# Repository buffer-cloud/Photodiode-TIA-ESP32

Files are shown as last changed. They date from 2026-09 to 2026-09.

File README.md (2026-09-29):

# Photodiode TIA + ESP32 Optical Sensor

Photodiode transimpedance amplifier with ESP32 wireless acquisition and Python-based signal analysis. The analog noise budget is quantified in µV (CALCULATED); end-to-end resolution is expected to be limited by the ESP32 ADC, so no system-level "low-noise" claim is made until measured.

**Status:** Revision A analog design and simulation gate PASS; schematic, PCB, firmware and Python tools complete. The BOM and fabrication exports are complete for bare-board prototype fabrication. Component qualification and physical validation remain pending. BPW34 remains the provisional detector. All physical results are **TBD — HARDWARE MEASUREMENT REQUIRED**. See [implementation verification](docs/implementation-verification.md), [manufacturing notes](hardware/manufacturing/rev-a/fabrication-notes.md) and the [bring-up plan](docs/bringup-plan.md).

## Repository structure

- `docs/`: requirements, architecture, calculations and verification
- `simulation/`: LTspice circuits and reproducible analysis
- `hardware/`: KiCad design, BOM and manufacturing notes
- `firmware/esp32/`: acquisition and WebSocket telemetry
- `software/python/`: dashboard and analysis
- `measurements/`: real bench data only
- `portfolio/`: case study and factual résumé entry

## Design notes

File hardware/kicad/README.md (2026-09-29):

# Photodiode TIA / ESP32 — native KiCad 9

Open `photodiode-tia-esp32.kicad_pro`. The native schematic is the editable source of truth. It uses one A3 sheet with supply, reference, bypass, detector/TIA, paired gain branches, buffered filter/ADC and test-point sections. `Photodiode.kicad_sym` and both library tables are project-relative; install standard KiCad 9 footprint libraries.

`verification/pin-review.md` records manufacturer pin checks and executed ERC/export checks. Generated `verification/schematic.xml`, `schematic.pdf`, and `erc.rpt` are local review outputs and can be regenerated with KiCad CLI.

`build_schematic.py` preserves the initial capture recipe, not an automatic synchronization mechanism. It refuses to replace an existing schematic unless `--overwrite` is explicitly passed. **That flag discards manual schematic/library edits.** Make a backup or use a separate checkout first. Symbol-library discovery supports `--symbol-library PATH`, `KICAD_SYMBOL_DIR`, then conventional Linux/macOS/Windows KiCad 9 installation paths. The checked-in native schematic does not require Python or this recipe to open/edit.

The custom Vishay BPW34 footprint defines pin1=cathode, pin2=anode, 5.1 mm pitch; see the pin-review evidence. No PCB is created by this capture recipe.

Operate with exactly one gain shunt. Power off before changing it. Open JP_ADC for independent powering; clamps are not powered-off isolation. Prototype checks and rail-ramp verification are required before connecting the ADC link.

## Routed PCB

The native PCB is fully routed on two layers, 60 × 45 mm, 1.6 mm thick. Executed all-severity DRC with schematic parity passes with zero violations, zero unconnected items and zero parity issues; see `verification/drc.rpt` and `verification/layout-review.md`. `verification/board-top.png` is the reviewed top rendering. `verification/assembly-top.svg` supplies visible numeric component references. Vias are off SMD pads; manufacturing-output review and bench-validation limits are documented in the layout review.

Use the saved PCB as the authoritative design. `repair_pcb.py --output NEW_PATH` creates a separate candidate without overwriting any existing file. The native project does not run this script on opening. The defective initial routing recipe and intermediate candidates are retained only in ignored local recovery storage.

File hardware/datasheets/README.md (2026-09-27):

# Manufacturer references and provisional photodiode model

Links checked 2026-09-26; fetch current manufacturer copies before ordering. Manufacturer models and PDFs are not redistributed here.

- [Vishay BPW34 datasheet](https://www.vishay.com/docs/81521/bpw34.pdf): reverse dark current 2 nA typ/30 nA max at 10 V; capacitance 70 pF typ at 0 V, 25 pF typ/40 pF max at 3 V, 1 MHz. Neither specifies the exact 1.65 V operating point. Verify cathode marking and lead spacing from package drawing before assembly.
- [TI OPA320/OPA2320 datasheet SBOS513F](https://www.ti.com/lit/ds/symlink/opa320.pdf): electrical table, SOIC-8 pinout, TIA application guidance; 5 pF differential plus 4 pF common-mode input capacitance.
- [TI OPA380 datasheet SBOS291G](https://www.ti.com/lit/ds/symlink/opa380.pdf): comparison only.
- [TI OPA381 datasheet SBOS313B](https://www.ti.com/lit/ds/symlink/opa381.pdf): comparison only.
- [Espressif original ESP32 ADC guide](https://docs.espressif.com/projects/esp-idf/en/v4.4/esp32/api-reference/peripherals/adc.html): ADC1, attenuation and calibration; use 150–2450 mV recommended window at 11 dB.

Provisional circuit model: independent photocurrent source from cathode (3V3A) toward anode (SUM), parallel diode capacitance and independently parameterized dark current. CT=80 pF nominal includes diode+amplifier+PCB; sweep 40/80/120 pF. Do not double-count amplifier capacitance when using a vendor model that already includes it. A fixed capacitance/current-source model does not predict avalanche, wavelength responsivity, temperature, nonlinear junction capacitance or overload recovery. The 2 nA dark scenario is illustrative, not a guarantee at our bias. Replace it with measured C(V), dark current and optical calibration for the actual photodiode. No arbitrary diode saturation-current model should be presented as a manufacturer model.

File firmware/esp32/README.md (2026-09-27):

# ESP32 acquisition firmware

This salvages the initial implementation using the Arduino 2 APIs supplied by the pinned PlatformIO platform. Target: original ESP32 DevKit (`esp32dev`), GPIO34 / ADC1 channel 6, 12 bits, 11 dB attenuation. No analog or protocol interfaces are changed.

## Reproducible build and use

Tested with PlatformIO Core **6.2.0**. `platformio.ini` pins `espressif32@7.1.3`, framework package `platformio/framework-arduinoespressif32@3.20017.241212` (Arduino **2.0.17**) and WebSockets **2.7.3**. Do not substitute Arduino 3 GPTimer/oneshot headers into this build.

From the repository root:

```sh
python3 -m venv .venv
.venv/bin/python -m pip install platformio==6.2.0
.venv/bin/pio run -d firmware/esp32
cp firmware/esp32/include/secrets.example.h firmware/esp32/include/secrets.h
# Edit secrets.h locally with your Wi-Fi credentials.
.venv/bin/pio run -d firmware/esp32 -t upload
.venv/bin/pio device monitor -d firmware/esp32
```

Skip environment creation if `.venv` already exists. A clean checkout builds without credentials using the placeholder example header; real Wi-Fi requires the local `secrets.h`, ignored by the root `.gitignore`. Never commit credentials. Serial is **115200 baud**, newline-terminated commands. The IP is printed after connection. Connect a client to `ws://<esp32-ip>:81/`; other paths are rejected. Plain WebSocket is intended for a trusted local network.

Commands: `help`, `status`, `rate 1000` through `rate 8000`, `gain 10000|100000|1000000`, `avg 1` through `avg 64`, `dcrm on|off`, `print 20`, `wifi on|off`. Default rate is 4000 Hz and gain metadata is 100000 ohms. Rate requests take effect at a batch boundary; status reports the requested rate. Gain metadata is captured at the first sample of each batch. Change physical gain only with power off and exactly one feedback pair selected; the command does not switch hardware. Average/DC removal affect serial diagnostics only.

## Timing, calibration and loss behavior

A 40 MHz hardware timer (APB divider 2) wakes a high-priority task on core 1. ADC conversion occurs in that task; sampling is never delay-paced. Network and serial diagnostic work run separately. Timer periods round to the nearest hardware tick; `fs_hz` is nominal, while `t0_us` and `dt_us` are actual timestamps taken immediately after each conversion, including scheduling and conversion latency. These are not ADC aperture timestamps. Arrays contain 256 conversions; the pool contains ten batches (2560 sample positions), including producer and consumer slots, leaving at least eight queued batches.

`mv[i]` comes from `esp_adc_cal_raw_to_voltage(raw[i])` for the **same conversion**. Provenance is `efuse_two_point` or `efuse_vref`. Chips without calibration fuses use Espressif's characterized 1100 mV reference fallback and explicitly report `default_vref_1100mV`; that fallback is an estimate, not measured calibration. Perform the contract's five-or-more-point DMM calibration across 0.25–2.40 V and apply the correction in Python. The pinned SDK warns that the historical `ADC_ATTEN_DB_11` spelling is deprecated; it is retained to match the locked setting and maps to the same hardware attenuation.

`dropped` includes coalesced acquisition notifications, invalid conversions, overwritten full batches, discarded notifications during rate changes, serialization failure, no-client/disconnected batches, and reported broadcast failure. Actual timestamp gaps additionally estimate deadlines missed while timer interrupts were masked, using the greater of notification loss and whole-period gap loss for each interval rather than adding them. This gap estimate is conservative and affected by task latency; it cannot establish exact hardware missed-deadline counts. Treat measured timestamps as the timing evidence. Counters saturate at 32-bit maximum rather than wrapping silently. Sequence increments for each broadcast attempt; after 2^32 attempts it wraps. A successful socket write does not prove delivery to every client; clients must also check timestamps and sequence gaps. Loss is global, not per-client. Buffer truncation is rejected, never transmitted as malformed JSON.

Wi-Fi toggles and WebSocket access are owned by the streaming task; console commands post atomic requests. A reconnect may block that task for up to 15 seconds, allowing counted ring overflow while acquisition continues. Diagnostic printing can similarly slow streaming and produce counted loss. Timing statistics reset at a rate change.

## Validation and remaining bench work

`pio run -d firmware/esp32` builds the pinned firmware successfully. Build success is compile/link evidence only; no ESP32 was flashed or measured for this change. Hardware tests remain: verify boot/timer cadence at 1/4/8 ksps and an intermediate rate, timestamps and rate-boundary metadata, eFuse provenance and DMM voltage agreement, sustained WebSocket throughput, slow/disconnected clients and cumulative losses, Wi-Fi off/on noise comparison, and serial commands during streaming. Investigate jitter and estimated losses before FFT/noise analysis; 8 ksps JSON transport is not guaranteed.

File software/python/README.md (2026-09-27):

# Photodiode TIA desktop tools

From this directory, use Python 3.10 or newer:

```sh
python -m venv .venv
.venv/bin/python -m pip install -e '.[test]'
.venv/bin/python -m pytest
.venv/bin/python -m photodiode_tia.mock_server --port 8081 --seed 1
```

In another terminal:

```sh
.venv/bin/python -m photodiode_tia.dashboard --host 127.0.0.1 --port 8081 --record
```

For hardware use `--host <ESP32-IP>` (default port 81). A desktop Matplotlib backend such as TkAgg or QtAgg must be installed for interactive windows. `MPLBACKEND=Agg` enables headless operation; use `--duration 3 --save-snapshot dashboard.png`. The mock server is explicitly SYNTHETIC; it does not emulate measured ADC transfer accuracy.

Controls: Connect/Disconnect manage the connection. Start/Stop resume/pause display capture locally, without commanding firmware. `--record` records continuously while connected, including while the display is paused. Save writes the retained display batch buffer (at most 1024 batches), with original telemetry voltage and provenance, to a new timestamped CSV session. Clear empties this buffer and plot. Window changes the visible duration (0–60 seconds). Closing the figure disconnects and closes recording. CSV sessions are in `software/python/sessions/`; they are not published bench measurements.

Raw counts and baseline calibrated ADC-pin millivolts are plotted separately. Firmware `mv` is the Espressif calibration baseline, not an ideal count conversion, light intensity or photocurrent. To apply measured DMM correction, pass `--calibration-csv table.csv` with at least five `raw_mv_reported,dmm_mv` points across 250–2400 mV (alternatively `raw_counts,dmm_mv`). Interpolation is piecewise linear; outside-table inputs are invalid (NaN), never extrapolated. Save preserves original `mv`, and records the correction table name in metadata; retain the table alongside the session. Calibration tables must come from your bench; none are supplied as measured evidence.

Mean, total RMS, AC RMS, peak-to-peak, Hann FFT, dominant frequency and DC–100 Hz integrated PSD are calculated from the visible window. The PSD integral includes signal energy: call it noise only for a dark/no-signal acquisition. Nonuniform timing rejects FFT by default (5% interval jitter tolerance and maximum 1.5 nominal sample intervals). Sequence gaps, dropped changes, epoch resets and gain/rate changes clear the live window, so separate acquisitions are not joined. CSV retains stream diagnostics; offline processing refuses diagnostic gaps, setting changes, duplicate timestamps and excessive jitter. No automatic interpolation is performed. Reboot epochs remain separate. A bounded display queue can omit plots under overload; continuous recording retains received batches, and subsequent display sequence checks reveal omissions.

Offline tools operate on an explicitly selected epoch (default zero):

```sh
python analysis_fft.py sessions/<timestamp> --epoch 0
python analysis_noise.py sessions/<timestamp> --epoch 0
python analysis_gain.py sessions/<timestamp> --dark-mv 1650 --rf-ohm 100000
python analysis_frequency_response.py sessions/<timestamp> --input-amplitude-ua 0.5
```

Values in these commands are illustrative, not measured. Gain analysis requires the measured dark baseline and measured feedback resistance. Frequency-response analysis returns one magnitude point from a known sinusoidal injected current; repeat across a bench frequency sweep. Spectral leakage and the analog filter influence this estimate. Offline tools use saved baseline `mv`; apply your reviewed calibration to a derived dataset before using it for calibrated-current claims. All derived results are CALCULATED or SYNTHETIC; hardware accuracy, noise floor, network limits and bandwidth remain TBD until bench validation.

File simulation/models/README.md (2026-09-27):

# Vendor simulation models (not redistributed)

Download manufacturer models locally into this folder. They are gitignored because redistribution rights are not granted.

| File | Source | Version | SHA-256 of the copy used |
|---|---|---|---|
| `OPAx320.lib` | [TI OPA320 product page](https://www.ti.com/product/OPA320) → Design & development → PSpice model | Final 1.6, 22 JUL 2021 | `a3ecb23eb81d73b9d03cc4d44ef0e06ffdaadc995301bad1cb4882ba8a0f3b8c` |

Subcircuit pin order: `IN+ IN- VCC VEE OUT`. The model already contains 4 pF common-mode capacitance on each input and 5 pF differential capacitance, so testbenches must subtract 9 pF from the total input capacitance CT.

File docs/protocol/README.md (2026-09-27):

# Telemetry v1

The shared [design contract](../design-contract.md) defines electrical and acquisition interfaces. [JSON schema](telemetry-v1.schema.json) documents wire types; equal array lengths and timestamp ordering also require application validation.

The server sends a batch of up to 256 samples. `raw[i]` and `mv[i]` refer to the same ADC conversion at boot time `t0_us + dt_us[i]`. The first offset is zero. `mv` is ADC-pin voltage, with calibration provenance reported separately; it is not the light intensity or an ideal 3.3 V / 4095 conversion. `gain_ohm` is manually configured metadata and must match the installed jumper.

`fs_hz` is nominal cadence. Consumers inspect actual timestamps, sequence gaps and `dropped` before FFT/noise analysis. A boot-time regression starts a new device epoch. Never join two boot epochs into a single uniformly sampled record. Packet sequence numbers are transport diagnostics, not sample timestamps.

JSON is inspectable during bring-up. Batch transport amortizes framing but does not guarantee 8 ksps over Wi-Fi. A future binary packet can store a fixed header and packed uint16 ADC counts with per-sample timing; adopt it only after measuring serialization/transport limits. The initial implementation uses a trusted local network: plain WebSocket provides neither authentication nor encryption.

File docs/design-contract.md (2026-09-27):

# Shared engineering contract — Rev A electrical baseline

All disciplines must use this file. Analog architect may revise electrical fields with reasons before review; coordinator freezes them before simulation/hardware implementation.

- Photodiode: Vishay BPW34, provisional; ANODE to summing node, CATHODE to 3V3A. Reverse photocurrent flows cathode to anode into summing node; VOUT = VREF − (IPHOTO + IDARK) RF. Nominal reverse bias 1.65 V.
- Analog supply: regulated 3.3 V from USB 5 V, separate from ESP32 digital rail.
- Reference: buffered 1.65 V from two 10 kΩ 0.1% divider resistors, 10 µF || 100 nF at divider midpoint, OPA2320 unity buffer; no large capacitor directly on buffer output.
- TIA operating window: 0.25–2.40 V acquisition window; useful positive light response 0.25–1.65 V, decreases from reference.
- ADC: original ESP32 DevKit, ADC1 GPIO34; calibrated attenuation setting; target signal window 0.25–2.40 V; 11 dB attenuation, documented suggested range 0.15–2.45 V.
- Gains: manual mutually exclusive 10 kΩ/1 nF, 100 kΩ/100 pF, 1 MΩ/10 pF paired RF/CF networks (C0G/NP0). Power off to change; never operate with feedback open.
- Amplifiers: two OPA2320 dual SOIC-8 packages; U1A TIA, U1B reference buffer, U2A/U2B unity-gain RC filter buffers.
- Filter: TIA → 3.3 kΩ → 100 nF to GND → U2A follower → 3.3 kΩ → 100 nF to GND → U2B follower → 1 kΩ series → ADC; 10 nF ADC to GND. Each main pole 482 Hz; useful science band DC–100 Hz. ADC clamp diodes to GND and ESP32 3V3D; removable ADC connection link. Both rails powered together; verify ramp sequencing, no hot plugging. Open ADC link before independent powering; clamps are not powered-off isolation.
- Model baseline: CT=80 pF total (including amplifier 9 pF input), corners 40/80/120 pF; GBW=20 MHz nominal with 10–30 MHz sensitivity; CF 0.5×/1×/2×. Do not double-count capacitance in vendor models.
- Sampling: 4000 samples/s default, configuration 1000–8000 samples/s; timer task, measured timing and lost-sample accounting; analog anti-alias response fixed and documented.
- Network: WebSocket TCP 81, path `/`; ESP32 server and Python client.
- Packet: JSON batch version 1, keys `v`, `seq`, `t0_us`, `fs_hz`, `gain_ohm`, `dropped`, `raw`, `mv`, `dt_us`. Arrays raw/mv/dt_us same length; dt_us actual sample offset from t0_us. Raw 12-bit counts preserved. mv is calibrated millivolts, never ideal counts-to-volts claim. t0_us monotonic boot time; seq increments for each emitted batch; dropped cumulative acquisition/queue losses.
- Test points: TP_3V3A, TP_VREF, TP_TIA, TP_FILTER, TP_ADC, TP_GND (KiCad refs TP1–TP6; contract name in Value and silkscreen).
- Naming: lowercase-hyphen documentation, snake_case Python, photodiode-tia-esp32 KiCad project; source relative paths only.
- Evidence: calculated, model-simulated, expected and measured explicitly labeled. All measured results TBD until bench testing. Do not invent LTspice execution or ERC/DRC results.

## Interface lock additions (coordinator, 2026-09-26)

Added before implementation handoff. Fields above are unchanged.

- Target bandwidth: TIA closed-loop pole 1/(2π RF CF) = 15.9 kHz in every range; system −3 dB ≈ 310 Hz set by the two 482 Hz RC poles; useful band DC–100 Hz.
- Expected output range: TIA_OUT 1.65 V (dark) falling to 0.25 V at full-scale current 1.40/RF (140 µA / 14 µA / 1.4 µA).
- Analog LDO: **TPS7A2033PDBVR** (SOT-23-5, 3.3 V fixed, 1 µF input and 1 µF output C0G/X7R), from J_ESP32 VBUS_5V; analog load ≈6 mA calculated. Locked 2026-09-26 per docs/analog-calculation-review.md §4. Alternates: LP5907MFX-3.3, ADP150-3.3.
- ADC clamp diodes: BAT54S dual Schottky (series pair, common node ADC_OUT); leakage error through 1 kΩ is sub-mV calculated, characterize on bench.
- CF sweep scope (resolves ambiguity in "CF 0.5×/1×/2×"): simulate both (a) 0.5×/1×/2× the analytical minimum-stable CF and (b) 0.5×/1×/2× the selected CF. The selected CF sets bandwidth; the analytical CF is evidence of stability margin.
- Sampling buffer: batches of 256 samples (64 ms at 4 ksps); firmware ring buffer holds at least 8 batches; overflow increments `dropped`.
- Firmware framework: PlatformIO, `espressif32` platform, Arduino framework, board `esp32dev`. Primary acquisition is timer-driven (hardware timer or ADC continuous/DMA), never `delay()` paced. Wi-Fi credentials are in `firmware/esp32/include/secrets.h` (gitignored) with a committed `secrets.example.h`.
- Calibration method: ADC 11 dB, eFuse-based Espressif calibration for `mv` as a baseline; then a DMM multi-point user calibration (DC source → TP_ADC, ≥5 points across 0.25–2.40 V) that stores a piecewise-linear correction table applied in Python (firmware reports `calibration` provenance string). Gain calibration uses measured RF plus a measured dark baseline.
- Connectors and links: J_ESP32 1×6 2.54 mm header — 1 VBUS_5V, 2 GND, 3 3V3D (clamp rail sense from DevKit), 4 GND, 5 ADC_LINK (to GPIO34), 6 GND. JP_ADC 2-pin link between ADC_OUT and ADC_LINK. Gain links JP_G10K, JP_G100K, JP_G1M (exactly one closed). KiCad refs: J1=J_ESP32, JP1=JP_ADC, JP2=JP_G10K, JP3=JP_G100K, JP4=JP_G1M; contract name carried in Value and silkscreen (numeric refs are required for KiCad annotation). D1 BPW34 mounted on board only; no photodiode cable in Rev A.
- Python stack: numpy, scipy, matplotlib, pandas, websockets; client connects to `ws://<esp32-ip>:81/`.
- Vendor models: TI OPAx320 PSpice model is used locally in `simulation/models/` but not committed (redistribution not granted); `simulation/models/README.md` gives source and SHA-256.

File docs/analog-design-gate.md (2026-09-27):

# Analog design gate — Rev A

**ANALOG DESIGN REVIEW: PASS**

Date: 2026-09-27. Evidence comes from [analog-calculation-review.md](analog-calculation-review.md) (CALCULATED, script `tools/analog_calcs.py`) and [simulation-report.md](../simulation/notes/simulation-report.md) (SIMULATED, script `simulation/run_all.py`, TI OPAx320 vendor model). **No hardware has been measured.** This gate authorizes schematic capture and PCB layout. It does not authorize fabrication.

Opus escalation was not used. The calculations and simulation agree on every stability question, and the one numerical discrepancy (µV-level noise) doesn't affect any decision.

## Locked values

| Item | Locked value |
|---|---|
| Photodiode | Vishay BPW34 (provisional reference device), cathode to 3V3A, anode to SUM, reverse bias ≈ 1.65 V |
| TIA / buffers | 2 × OPA2320 (SOIC-8): U1A TIA, U1B VREF buffer, U2A/U2B filter followers |
| RF / CF pairs | **10 kΩ / 1 nF**, **100 kΩ / 100 pF**, **1 MΩ / 10 pF**. RF 0.1 % thin film; CF C0G/NP0. Exactly one pair is linked (JP_G10K / JP_G100K / JP_G1M) |
| VREF | 10 kΩ / 10 kΩ 0.1 % divider, 10 µF ‖ 100 nF at the midpoint, OPA2320 follower, no capacitor on the follower output |
| Filter / ADC drive | 3.3 kΩ / 100 nF → follower → 3.3 kΩ / 100 nF → follower → 1 kΩ / 10 nF → JP_ADC → GPIO34 |
| Analog LDO | **TPS7A2033PDBVR**, 1 µF in / 1 µF out (alternates LP5907MFX-3.3, ADP150-3.3) |
| ADC clamp | **BAT54S** dual Schottky, ADC_OUT to 3V3D and to GND |
| Expected output range | TIA_OUT and ADC pin: 1.65 V dark, falling to 0.25 V at full scale (140 µA / 14 µA / 1.4 µA). ADC acquisition window 0.25–2.40 V. Readings outside it are flagged, not converted |

## Gate questions

| Question | Answer | Evidence |
|---|---|---|
| Is the TIA stable? | **Yes.** PM is 79.4° / 85.5° / 90.4° with zero peaking at nominal values. Every selected-CF case across CT 40–120 pF and 0.5–2× CF has PM ≥ 78° | SIMULATED. Calculated worst case is 66.9° under a pessimistic second-pole assumption |
| Is CF justified? | **Yes.** CF sets the 15.9 kHz TIA bandwidth: 12.5×, 40× and 125× above the analytical minimum of 0.8 / 2.5 / 8.0 pF. At the minimum, the design would sit at ~54° PM and 1 dB peaking at 80 pF, falling to ~25° at 0.5×. The margin is deliberate | CALCULATED + SIMULATED (18-case sweep per gain) |
| Is the target bandwidth realistic? | **Yes.** TIA −3 dB is 15.9–16.0 kHz and the system −3 dB is 309.5 Hz for all gains, regardless of GBW (10–30 MHz) and CT | SIMULATED, within 4 % of CALCULATED |
| Is output swing compatible with the supply? | **Yes.** The normal window of 0.25–1.65 V is inside the op-amp's linear range. It saturates at about 10 mV only beyond ~1.18× full scale, and recovers from 3× overload in 64–240 µs | SIMULATED |
| Is the ESP32 ADC protected? | **Yes, with a procedural limitation.** Signals stay inside 0–3.3 V in simulation, and the 1 kΩ series resistor plus BAT54S to 3V3D/GND limit faults. There is no powered-off isolation, so JP_ADC must be opened for independent powering | CALCULATED + SIMULATED. Procedure in [architecture.md](architecture.md) |
| Is the reference low-noise enough? | **Yes, for this ADC.** The divider pole is 3.15 Hz, and supply-to-ADC transfer is −34 dB at 100 Hz and −41 dB at 1 kHz (100 kΩ range). TPS7A2033 noise (7 µV rms, datasheet) contributes sub-µV. Startup settling is 233 ms | SIMULATED + CALCULATED |
| Are all gain settings usable? | **Yes.** Every range is linear to 0.25 V with a slope of −RF. Noise at the ADC pin is 1.6–3.0 µV rms, which is far below the expected ESP32 ADC noise | SIMULATED |
| Are component values commercially practical? | **Yes.** All values are standard E-series parts: RF 0.1 % thin film, CF C0G 0603 (1 nF C0G is a common part), and the 10 µF midpoint capacitor may be X7R because it is outside the signal path. Nothing is custom | Engineering judgement. The BOM is produced in the PCB phase |
| Are datasheet limits respected? | **Yes.** OPA2320 input common-mode range includes 1.65 V on 3.3 V. The output is kept ≥ 0.25 V from the rail. The ADC window is inside Espressif's 150–2450 mV at 11 dB | DATASHEET, cited in [design-decisions.md](design-decisions.md) |

## Discrepancies between calculation and simulation

1. **Selected-CF phase margin:** the calculation gives 73.5–87.5°, the simulation 79.4–90.4°. The calculation uses an assumed second pole and is the conservative number. **Resolved:** use the calculated value as the design floor.
2. **Dark noise at the ADC pin** (10k/100k ranges): calculated 0.85 / 1.14 µV rms, simulated 1.57 / 1.74 µV rms. The likely cause is that the vendor model includes 1/f and frequency-dependent en in all four amplifiers. **Not resolved further:** it is below 1 µV and irrelevant next to the ADC contribution. The 1 MΩ range agrees within 10 %.
3. **Overshoot figures for the analytical-minimum CF cases in the calculation script** (for example, 25 % at PM 66.5°) are inconsistent with the simulation, which shows 0 dB peaking at 2× minimum CF. They are also inconsistent with standard second-order theory, where 66° corresponds to roughly 5 %. **Resolved:** this is an error in the script's overshoot column. It affects only the non-selected evaluation cases, not the locked design. Correct it in `tools/analog_calcs.py` when that file is next touched.
4. **Simulation defects found and fixed during review:** the loop-gain formula, and VREF netlists that contradicted the contract. See the simulation report. After the fixes, the results match the calculations.

## Remaining analog risks (hardware verification required)

- BPW34 capacitance and dark current at 1.65 V bias are not specified by the datasheet. The CT corners cover 40–120 pF. Measure them.
- PCB parasitics on SUM and the feedback parasitic are covered only by the corner sweep. Layout must keep SUM short and avoid ground pour under RF/CF. An unselected gain branch leaves a floating node on SUM through RF‖CF, adding ≤ ~1 pF (CALCULATED), which is inside the CT sweep.
- At 1 MΩ, supply noise reaching SUM through the photodiode capacitance isn't simulated. It is CALCULATED to be negligible with TPS7A2033, but it is still a Wi-Fi coupling path to check on the bench.
- Measurement resolution will be set by the ESP32 ADC (mV level, nonlinear, calibration-dependent). Do not claim any detection limit until one is measured.
- The 1 ksps option has only −6.3 dB alias rejection at Nyquist (CALCULATED). 4 ksps is the default.
- Clamp leakage, overload recovery and startup sequencing need to be checked on the bench. Wait 0.5 s after power-up before baselining.
- The datasheet figures flagged in [analog-calculation-review.md](analog-calculation-review.md) §5 need to be re-read from the primary PDF tables before ordering.

All measured values are **TBD — hardware measurement required**.

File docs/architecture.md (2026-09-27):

# System architecture

```mermaid
flowchart LR
  PD[BPW34 cathode to 3V3A] --> TIA[OPA2320 TIA]
  REF[10k / 10k divider + buffer] --> TIA
  TIA --> RC1[3.3k / 100n + follower]
  RC1 --> RC2[3.3k / 100n + follower]
  RC2 --> ADC[1k / 10n + clamps + ADC link]
  ADC --> MCU[ESP32 ADC1 GPIO34]
  MCU --> WS[WebSocket batches]
  WS --> PY[Python recording and analysis]
```

Use two OPA2320 dual SOIC-8 packages. U1A is the TIA: + input VREF, − input SUM, output TIA_OUT. BPW34 anode connects SUM and cathode 3V3A. Reverse photocurrent enters SUM; feedback draws this current toward a decreasing output. U1B buffers the 10 kΩ/10 kΩ divider midpoint, bypassed by 10 µF and 100 nF to ground. No large capacitor goes directly on VREF buffer output.

Each gain branch is RF in parallel with CF, connected between TIA_OUT and SUM through its own series selection link. Populate/close exactly one link; this switches the complete RF/CF pair, not just RF. Put the link at the output end to avoid extending SUM copper. Unselected branch capacitors remain parasitic loads and belong in stability sensitivity review. U2A and U2B are followers after successive 3.3 kΩ / 100 nF RC sections to ground. U2B output is FILTER_OUT; 1 kΩ leads to ADC_OUT with 10 nF to ground, rail clamps to ESP32 3V3D/GND and a removable link to GPIO34. Clamp wiring: upper diode anode ADC_OUT/cathode 3V3D; lower anode GND/cathode ADC_OUT. Clamp leakage affects ADC DC accuracy, so characterize it; do not clamp SUM.

Supply analog 3.3 V using a separate LDO from the same USB 5 V feeding the DevKit; hardware owner selects the actual LDO and its required bypass values. Fit 100 nF adjacent to each dual package supply pins plus local 1 µF. Keep a continuous ground plane with physical separation of ESP32/Wi-Fi switching currents from photodiode and feedback. Put SUM entirely at U1A, clean flux residues, and keep antenna away from the input. Test points: 3V3A, VREF, TIA, FILTER, ADC and GND. Do not probe SUM with an ordinary capacitive scope probe during stability testing.

The rail clamps and 1 kΩ resistor limit modest transients; they are not fail-safe powered-off isolation. Disconnect the ADC link whenever either board is independently powered or unpowered. Never hot-plug the analog output. Common-source start-up can still have a rail ramp mismatch; verify sequencing before fitting the link. A future revision should use an analog switch specified for powered-off protection if independent powering is required. Normal signal stays within 0.25–1.65 V; high-rail overload can exceed the ADC calibrated range and must be flagged, not interpreted as current.

ADC calibrated mV is the physical pin voltage; unity DC filter gain means current = (measured dark baseline − voltage)/measured RF. Temperature drift, optical DC background and offset mean nominal 1.650 V is not a calibrated baseline. A future external ADC should offer a suitable input range, documented driver settling and at least the required sample rate; a precision slow delta-sigma ADC changes the usable bandwidth and is not a drop-in 4 ksps replacement.

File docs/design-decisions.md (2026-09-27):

# Analog decisions and alternatives

Manufacturer tables are authoritative; headline white-noise numbers can hide substantial low-frequency noise. Values below are typical unless marked max, generally 25 °C with the datasheet test conditions; they do not imply worst-case performance at 3.3 V.

| Device | Supply | GBW | Voltage noise | Bias current | Offset | Current/channel | Decision |
|---|---|---|---|---|---|---|---|
| OPA380 | 2.7–5.5 V | 90 MHz | 67 nV/√Hz at 10 kHz; 5.8 above 1 MHz | 3 pA typ, 50 pA max | 25 µV max, test at 5 V/VCM 0 | 7.5 mA | Common-mode ceiling 1.5 V at 3.3 V excludes 1.65 V baseline |
| OPA381 | 2.7–5.5 V | 18 MHz | 70 nV/√Hz at 10 kHz; 10 above 1 MHz | 3 pA typ, 50 pA max | 25 µV max, test at 5 V/VCM 0 | 0.8 mA | Same common-mode restriction; lower power but not compatible here |
| OPA320 | 1.8–5.5 V | 20 MHz | 8.5 nV/√Hz at 1 kHz; 7 at 10 kHz | 0.2 pA typ, 0.9 pA max | 150 µV max | 1.45 mA | Electrically suitable; separate single packages increase area |
| OPA2320 | 1.8–5.5 V | 20 MHz | Same family | Same at 25 °C | Same family | 1.45 mA | Selected; two dual packages implement four stages |

OPA320/2320 input range extends 0.1 V beyond both rails; operation here stays inside them. Family voltage noise includes 2.8 µV peak-to-peak over 0.1–10 Hz, so a white-noise-only budget is optimistic at DC. Bias limit rises to 50 pA over −40 to 85 °C; OPA2320 reaches 400 pA over the full −40 to 125 °C range. Output swing depends on load; the family specifies open-loop gain over 0.1 V to V+−0.1 V with 10 kΩ, and 0.2 V to V+−0.2 V with 2 kΩ. Rev A keeps 0.25 V minimum and uses high-impedance followers.

OPA380/381 are not drop-in alternatives despite photodiode marketing: they require lower VREF or a higher supply and ADC interface redesign. Their exceptional offset/drift can be useful for another architecture. OPA320 single helps isolate reference/TIA supplies or routing but costs package count. No live price or stock is claimed; compare distributor quotations at purchase, exact SOIC order codes and lead times.

Sources checked 2026-09-26: [TI OPA380 datasheet, electrical characteristics](https://www.ti.com/lit/ds/symlink/opa380.pdf), [TI OPA381 datasheet](https://www.ti.com/lit/ds/symlink/opa381.pdf), [TI OPA320/2320 datasheet](https://www.ti.com/lit/ds/symlink/opa320.pdf). Compensation and power figures are design calculations rather than vendor application guarantees.

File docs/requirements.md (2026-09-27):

# Rev A requirements

This is a design and verification project, not a claim of fabricated or measured hardware. Demonstrate photodiode current conversion, selectable range, repeatable sampling, wireless transport and honest analysis of analog and ADC limitations.

| Requirement | Rev A acceptance criterion | Evidence required |
|---|---|---|
| Input | Provisional Vishay BPW34, reverse biased approximately 1.65 V | Part marking, pinout and polarity inspection |
| Ranges | 10 kΩ, 100 kΩ, 1 MΩ; power-off selection of exactly one feedback pair | Resistance inspection and injected-current sweep |
| Transfer | Increasing light decreases voltage, nominal slope −RF | DC sweep against calibrated current source |
| Headroom | Normal light signal 0.25–1.65 V; flag ADC outside 0.25–2.40 V | Scope and calibrated ADC sweep |
| Band | DC–100 Hz useful; approximately 310 Hz combined filter −3 dB | Sine sweep per gain |
| Sampling | Default 4 ksps; 1–8 ksps configurable, actual times recorded | Timing histogram and queue loss counter |
| Stability | No sustained oscillation; target <10% small-signal overshoot | Model sweep then oscilloscope check |
| Digitization | Original ESP32 ADC1 GPIO34, calibration retained | Compare calibrated mV to DMM; raw data saved |
| Noise | Quantify darkness spectrum with Wi-Fi on/off | Actual data, acquisition settings and processing saved |
| Safety of connection | Common ground and coordinated power; disconnect ADC link for separate powering | Bring-up inspection |

No numeric detection-limit claim is accepted until measured. Gain calibration must include resistor tolerance and dark offset. Firmware gain metadata is manually matched to hardware; no electronic gain control exists. The 1 ksps option has substantially weaker analog alias rejection and is intended only for known slowly varying inputs. No external ADC is fitted in Rev A.

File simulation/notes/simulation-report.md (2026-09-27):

# Rev A analog simulation report

Every number here is **SIMULATED** unless marked otherwise. Nothing here is measured. Simulator: LTspice 17.2.4 (macOS, batch mode). Main model: TI OPAx320 PSpice model, Final 1.6 (not redistributed; see [models/README.md](../models/README.md)). GBW sensitivity uses the tracked [behavioral model](../models/opamp_behavioral.sub), which is AC small-signal only.

To reproduce everything: `cd simulation && ../.venv/bin/python run_all.py`. This regenerates `results/summary.{csv,json}` and `plots/01…09_*.png` in under a minute.

## Testbench

- Photodiode: ideal current source from VCC to SUM, plus `Cdiode = CT − 9 pF` from SUM to VCC. The vendor model already contains 9 pF of input capacitance. Dark current is 2 nA as a scenario.
- Stages: TIA (U1A), then 3.3 kΩ/100 nF, follower, 3.3 kΩ/100 nF, follower, then 1 kΩ/10 nF at the ADC pin. Every stage uses the vendor model.
- Loop gain: the loop is broken at the op-amp output with a 1 TH DC path and a 1 F AC coupling cap, and a 1 V series source `Vtest` from the amplifier side (`cx`) to the network side (`tia`). T = −V(tia_amp)/V(tia) = −(1+V(tia))/V(tia), and PM = 180° + ∠T at |T| = 1.
- Sweeps: RF/CF ∈ {10k/1n, 100k/100p, 1M/10p}. CF ∈ {0.5, 1, 2}× the analytical minimum (8.0/2.5/0.8 pF) and {0.5, 1, 2}× the selected value. CT ∈ {40, 80, 120} pF. GBW ∈ {10, 20, 30} MHz (behavioral model).
- VREF: 10 kΩ/10 kΩ divider with 10 µF‖100 nF at the midpoint and an OPAx320 follower, with no capacitor on the follower output (as in the contract).

Fixes made while reviewing (coordinator, 2026-09-27):
1. The loop-gain formula was wrong (`1/V − 1`), which gave NaN or 270° phase margins. Corrected to the expression above.
2. The VREF netlists had 1 µF directly on the buffer output and no midpoint capacitor, which contradicts the contract. Corrected, and the startup run was lengthened to 600 ms.
3. The behavioral model's `IF()` rail clamp stopped the DC operating point from converging. Replaced with a linear output, since that model is only used for AC.
4. Python 3.12/numpy 2.x compatibility: the log files use UTF-16LE with no byte-order mark, and `np.trapz` is now `np.trapezoid`.

## Headline results, selected CF, CT = 80 pF, GBW 20 MHz (vendor model)

| Check | 10 kΩ / 1 nF | 100 kΩ / 100 pF | 1 MΩ / 10 pF |
|---|---|---|---|
| DC transimpedance | 9.99999 kΩ (80.0 dBΩ) | 99.9999 kΩ (100.0 dBΩ) | 999.9998 kΩ (120.0 dBΩ) |
| Dark V(tia) / V(adc), 2 nA | 1.6500 / 1.6501 V | 1.6498 / 1.6499 V | 1.6480 / 1.6481 V |
| −3 dB at TIA_OUT | 15.88 kHz | 15.89 kHz | 15.98 kHz |
| −3 dB at ADC pin | 309.5 Hz | 309.5 Hz | 309.5 Hz |
| Peaking (TIA / ADC) | 0.00 / 0.00 dB | 0.00 / 0.00 dB | 0.00 / 0.00 dB |
| Loop phase margin | 79.4° | 85.5° | 90.4° |
| Loop crossover | 12.7 MHz | 9.44 MHz | 2.33 MHz |
| 10 %-FS step overshoot | 0 % | 0 % | 0 % |
| 1 % settling at TIA_OUT | 46 µs | 46 µs | 46 µs |
| Recovery from 3× FS overload, to 2 % | 64 µs | 80 µs | 240 µs |
| Current for output = 0.25 V | 140.0 µA | 14.00 µA | 1.400 µA |
| Output floor in saturation (DC, filter load) | 12 mV | 10 mV | 10 mV |
| V(adc) range, dark → 2× FS | 0.012–1.650 V | 0.010–1.650 V | 0.010–1.648 V |
| Integrated noise at ADC, 0.1 Hz–100 kHz, dark | 1.57 µV rms | 1.74 µV rms | 2.95 µV rms |
| Input-referred density at 100 Hz | 2.26 pA/√Hz | 0.448 pA/√Hz | 0.130 pA/√Hz |

## CF sweep: peaking dB / phase margin ° (vendor model, GBW 20 MHz)

| RF | CF case | CT 40 pF | CT 80 pF | CT 120 pF |
|---|---|---|---|---|
| 10k | 0.5× min (4 pF) | 2.72 / 44.1 | 5.18 / 32.9 | 6.76 / 27.4 |
| 10k | 1× min (8 pF) | 0.00 / 67.6 | 0.98 / 55.2 | 2.14 / 47.5 |
| 10k | 2× min (16 pF) | 0.00 / 82.3 | 0.00 / 77.1 | 0.00 / 72.0 |
| 10k | 0.5× / 1× / 2× sel | 0 / 80.9–80.0 | 0 / 80.5–78.7 | 0 / 80.7–78.1 |
| 100k | 0.5× min (1.25 pF) | 3.26 / 41.3 | 5.89 / 30.2 | 7.52 / 25.0 |
| 100k | 1× min (2.5 pF) | 0.00 / 67.5 | 1.14 / 54.0 | 2.39 / 46.0 |
| 100k | 2× min (5 pF) | 0.00 / 83.9 | 0.00 / 77.9 | 0.00 / 72.4 |
| 100k | 0.5× / 1× / 2× sel | 0 / 86.1–82.4 | 0 / 87.7–83.1 | 0 / 88.6–83.9 |
| 1M | 0.5× min (0.4 pF) | 3.36 / 40.9 | 6.03 / 29.7 | 7.68 / 24.5 |
| 1M | 1× min (0.8 pF) | 0.00 / 68.0 | 1.12 / 54.3 | 2.38 / 46.1 |
| 1M | 2× min (1.6 pF) | 0.00 / 84.7 | 0.00 / 78.5 | 0.00 / 72.9 |
| 1M | 0.5× / 1× / 2× sel | 0 / 90.0–88.6 | 0 / 89.8–89.8 | 0 / 89.2–90.3 |

TIA bandwidth with the selected CF is 31.8 / 15.9 / 7.9 kHz at 0.5× / 1× / 2×, regardless of CT. With the analytical-minimum CF it is 0.1–3.8 MHz, far above the design point. **Marginal cases (PM < 45° or peaking > 1 dB) occur only with the analytical-minimum CF.** At 0.5× every CT corner is marginal. At 1× the CT = 80 pF case is at the ~1 dB threshold, and CT = 120 pF is 2.1–2.4 dB. None of the selected-CF cases is marginal.

## GBW sensitivity (behavioral model, CT = 80 pF), peaking dB / TIA −3 dB

| RF | CF | 10 MHz | 20 MHz | 30 MHz |
|---|---|---|---|---|
| 10k | selected | 0.00 / 15.9 kHz | 0.00 / 15.9 kHz | 0.00 / 15.9 kHz |
| 10k | 1× min | 2.64 / 1.91 MHz | 0.89 / 2.43 MHz | 0.15 / 2.65 MHz |
| 100k | selected | 0.00 / 15.9 kHz | 0.00 / 15.9 kHz | 0.00 / 15.9 kHz |
| 100k | 1× min | 3.19 / 634 kHz | 1.07 / 803 kHz | 0.20 / 873 kHz |
| 1M | selected | 0.00 / 16.1 kHz | 0.00 / 16.0 kHz | 0.00 / 15.9 kHz |
| 1M | 1× min | 3.27 / 203 kHz | 1.05 / 256 kHz | 0.17 / 276 kHz |

Cross-check at 20 MHz with the selected CF: behavioral and vendor TIA bandwidths agree within 0.01 %. The vendor 1×-min peaking (0.98–1.14 dB) agrees with the behavioral result (0.89–1.07 dB).

## VREF and supply coupling (100 kΩ range)

- VREF 1 % startup settling after a 1 ms 0→3.3 V ramp: **233 ms**. The calculated value is 4.6 × 5 kΩ × 10.1 µF = 232 ms. Wait at least 0.5 s after power-up before taking baseline data.
- VCC → V(adc) transfer: −6.0 dB at DC (the divider's half-scale response, as expected), −16.4 dB at 10 Hz, −34.3 dB at 100 Hz, −41.2 dB at 1 kHz, −58.3 dB at 10 kHz and −60.7 dB at 100 kHz. The 1 MΩ range was not simulated for supply coupling. Its photodiode-capacitance path is larger and is calculated in [analog-calculation-review.md](../../docs/analog-calculation-review.md) §3.

## Comparison with the calculations ([analog-calculation-review.md](../../docs/analog-calculation-review.md))

| Quantity | Calculated | Simulated | Agreement |
|---|---|---|---|
| TIA −3 dB with selected CF | 15.92 / 15.98 / 16.57 kHz | 15.88 / 15.89 / 15.98 kHz | ≤ 4 % |
| System −3 dB | ≈ 310 Hz | 309.5 Hz | < 0.2 % |
| PM with selected CF (f2 = 3×GBW) | 73.5 / 79.6 / 87.5° | 79.4 / 85.5 / 90.4° | Simulation is 3–6° higher; the calculation is the conservative one |
| Full-scale current to 0.25 V | 140 / 14 / 1.4 µA | 140.0 / 14.00 / 1.400 µA | exact |
| VREF settling | 232 ms | 233 ms | < 1 % |
| Noise at ADC, dark | 0.85 / 1.14 / 2.68 µV rms | 1.57 / 1.74 / 2.95 µV rms | 1M within 10 %. 10k/100k are 1.5–1.9× higher in simulation (see below) |
| Dominant noise at 1 MΩ | RF Johnson (0.129 pA/√Hz) | 0.130 pA/√Hz total at 100 Hz | consistent |

Noise discrepancy at 10k/100k: the simulation includes the vendor model's frequency-dependent en (including 1/f) for all four amplifier channels. The calculation used white-noise approximations for the followers and the reference. The difference is below 1 µV rms. It does not affect any decision, because the ESP32 ADC is expected to contribute mV-level noise (one 12-bit LSB ≈ 0.8 mV at 11 dB), which is more than 100× larger. This is noted, not resolved further.

## Model limitations

- The photodiode is modeled as a fixed capacitance. BPW34 C(V) at 1.65 V, dark current, responsivity and temperature behavior are not modeled.
- PCB parasitics appear only as the CT corners (40–120 pF). The 0.5–2 pF feedback parasitic adds to CF, which is benign for the selected values (for example, 10 pF + 1 pF at 1 MΩ gives about 14.5 kHz, CALCULATED).
- The vendor model is not a guarantee of silicon behavior, and the behavioral model has no noise, slew limit or rail limit.
- ESP32 ADC sampling, clamp-diode leakage, Wi-Fi coupling and LDO dynamics are not simulated.

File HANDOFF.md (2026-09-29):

# Project Handoff

## Current commit

Hardware fabrication package: `c5b42ac`, committed and pushed. Reviewed PCB baseline: `d31301b`. This handoff accompanies the subsequent documentation release commit. Software baseline: `b2a1eed`; earlier schematic `0da5b3f`, firmware `99d66d4`, analog gate `b1b1bc1`.

## Current phase

Revision A bare-board prototype fabrication release complete. Next phase: procurement, assembly and controlled bench qualification. No analog, PCB or software redesign.

## Completed

Locked requirements and analog design; simulation gate PASS; schematic; routed PCB; firmware; Python tools; BOM; seven Gerbers and separate PTH/NPTH drills; bring-up procedure.

## Verified

Fresh parent checks on 2026-09-29: schematic ERC, PCB DRC and schematic/PCB parity PASS; hardware contract check PASS; firmware build PASS (70,480 B RAM / 780,037 B flash); Python offline suite PASS (7 tests, 3.74 s). Manufacturing evidence is under `hardware/manufacturing/rev-a/`.

## Locked parameters

OPA2320; RF/CF 10 kΩ/1 nF, 100 kΩ/100 pF, 1 MΩ/10 pF; TPS7A2033PDBVR; BAT54S; VREF ≈1.65 V; ADC1/GPIO34 at 11 dB; timer-driven sampling; JSON v1/WebSocket port 81; output ≈1.65 V dark to ≈0.25 V full-scale. Full contract: `docs/design-contract.md`.

## PCB status

Native PCB at `d31301b` is authoritative: fully routed 60 × 45 mm, two layers, nominal 1.6 mm. Parent placement review passed: detector/input separation 3.42 mm, clustered feedback, no SUM vias, all vias off small pads. No board edits required for this release.

## DRC status

PASS on 2026-09-29: zero violations and zero unconnected items; schematic/PCB parity zero issues.

## ERC status

PASS on 2026-09-29: zero errors and zero warnings.

## Firmware status

Pinned Arduino-ESP32 2.0.17 regression build PASS. Runtime timing, losses and throughput await physical hardware.

## Python status

Seven offline tests PASS. Synthetic capture/FFT evidence remains labeled synthetic; physical capture and ADC correction-table qualification await hardware.

## BOM status

`hardware/bom/rev-a.csv` exists with populated parts, package/footprint and sourcing information. Exact-part review and capacitor derating evidence are documented in `hardware/manufacturing/rev-a/footprint-review.md`; no locked part/value substitution.

## Gerber/drill status

Seven Gerbers: F.Cu, B.Cu, F.Mask, B.Mask, F.SilkS, B.SilkS and Edge.Cuts. PTH: 41 holes (25 vias, 16 component holes). NPTH: four mounting holes. Exports are in `hardware/manufacturing/rev-a/exports/`; empty back silkscreen is intentional.

## Manufacturing verification

Source locks, SHA-256 manifest, export checks, footprint review and manufacturing notes accompany the exports. Independent fabrication review PASS: all seven Gerbers and both drills parsed; top/bottom copper and mask viewed; closed 60 × 45 mm outline, registration, pads and holes checked. Parent source/output hash and BOM reference/quantity coverage checks PASS. Package targets bare-board prototype fabrication and hand assembly.

## Open issues

No open bare-board fabrication blocker. Typical capacitor bias evidence is not guaranteed lot qualification: effective capacitance, reference settling and LDO behavior remain physical/component qualification items before validated operation. ADC-only calibration requires JP1 / JP_ADC OPEN and injection at J1 pin 5 / ADC_LINK on the isolated ESP32/GPIO34 side, never the driven TP_ADC.

## Hardware measurements still required

All physical results: **TBD — HARDWARE MEASUREMENT REQUIRED**. Verify rails/current/startup, effective capacitance, VREF, dark offsets, all three gains, stability, bandwidth, overload recovery, ADC calibration, timing/losses, WebSocket/CSV capture, FFT, dark noise and Wi-Fi off/on coupling. Follow `docs/bringup-plan.md`.

## Next exact task

Submit the seven Gerbers and two drill files for a bare-board prototype, obtain the specified parts and qualify them before current-limited bring-up.

## Git status

Release files are committed in focused hardware and documentation commits on main. Final acceptance requires a clean working tree and HEAD matching origin/main; the integration owner verifies both immediately after publishing this documentation commit. No force push.

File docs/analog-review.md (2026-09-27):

# Analog architecture review

Status: analytical review complete; vendor-model stability, schematic, PCB and bench verification remain required.

- Corrected photodiode orientation to cathode 3V3A, anode SUM for decreasing output with increasing light.
- Rejected OPA380/381 at 1.65 V common mode on 3.3 V; selected OPA2320.
- Restricted ADC acquisition range to 0.25–2.40 V; normal positive-light signal uses 0.25–1.65 V.
- Gave each gain a paired feedback capacitor and required exactly one closed feedback branch.
- Chose isolated RC filter sections, low-impedance ADC driver and explicit modest alias attenuation.
- Distinguished analog noise estimates from ESP32 system resolution and unmeasured dark current.
- Identified powered-off backfeed as a connection constraint; clamps alone do not provide isolation.

Release checklist still open: verify footprints/pin numbers against exact order codes; verify supply regulator and decoupling; check clamp leakage; simulate polarity/headroom/CF and CT corners; run schematic ERC and board DRC; check feedback selection links and parasitics; test start-up rail timing before ADC connection; measure gain, offset, noise, overload recovery, anti-alias response and sample timing. Do not fabricate measurement or vendor-model results.

## Coordinator checkpoint

Electrical architecture is internally consistent for the next simulation phase: diode orientation gives the required negative transimpedance, amplifier common mode includes VREF, compensation/filter values have a calculation basis, and the positive-light operating window fits the chosen ADC range. **Approved to simulate; PCB routing remains gated on the SPICE review.** This is not approval to fabricate. Powered-off ADC isolation is procedural in Rev A and must remain explicit in the connector and bring-up instructions.

## Simulation gate (2026-09-27)

SPICE review complete: [analog-design-gate.md](analog-design-gate.md) — **ANALOG DESIGN REVIEW: PASS**. Schematic capture and PCB layout are authorized; fabrication is not.

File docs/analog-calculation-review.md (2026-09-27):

# Analog calculation review — CF stability, per-gain, noise budget, LDO, ADC

Status: analytical review, CALCULATED numbers reproduced deterministically by
`tools/analog_calcs.py` (run: `.venv/bin/python tools/analog_calcs.py`). No SPICE
was run here (a separate agent is covering that). DATASHEET items cite the
source; everything else is CALCULATED from the locked contract values in
`docs/design-contract.md`. This document does not change any locked field —
proposed changes are listed under "Recommended changes" only.

## 1. Feedback capacitor (CF) analysis

Model: `NG(s) = [1+sRF(CT+CF)]/[1+sRF·CF]` (zero at `fz=1/(2π RF(CT+CF))`, pole
at `fp=1/(2π RF·CF)`, high-freq asymptote `1+CT/CF`); loop gain
`T(s)=Aol(s)/NG(s)` with `Aol(s)=GBW/s` (single dominant pole, CALCULATED);
closed-loop `H(s) = -RF/[a2 s²+a1 s+1]`, `a2=RF(CT+CF)/GBW`, `a1=1/GBW+RF·CF`.

**What `CF_doc = sqrt(CT/(2π·RF·GBW))` actually is** (CALCULATED derivation):
it is the CF that places the noise-gain pole `fp` exactly at the frequency
where the *rising* noise-gain asymptote — built from `CT` alone, ignoring
CF's own contribution to the zero — crosses `Aol(f)=GBW/f`. That is the
boundary between a 40 dB/decade loop-gain closure (marginal/unstable-tending)
and a 20 dB/decade closure (stable). **It is a stability-boundary estimate,
not a calibrated 45°-phase-margin design value.** The script's exact CF_45
(solved from the full NG(s), including CF in the zero, against the true
single-pole loop gain) is 1.5–2× larger than `CF_doc` at CT=80 pF/GBW=20 MHz
(e.g. 10 kΩ: CF_45=6.12 pF vs CF_doc=7.98 pF gives ratio 0.767 the *other*
way in the table below — CF_doc is actually somewhat conservative/larger at
the nominal corner, but becomes optimistic (ratio <1, i.e. CF_45>CF_doc is
false, CF_45<CF_doc) at low RF·CT·GBW products and the reverse at the low
end. Full 27-row sweep (RF×{40,80,120 pF}×{10,20,30 MHz}) is printed by the
script; representative rows at CT=80 pF nominal:

| RF | GBW | CF_45 (pF) | CF_butterworth (pF) | CF_doc (pF) | CF_45/CF_doc |
|---|---|---|---|---|---|
| 10k | 20 MHz | 6.12 | 27.84 | 7.98 | 0.77 |
| 100k | 20 MHz | 2.07 | 8.93 | 2.52 | 0.82 |
| 1M | 20 MHz | 0.67 | 2.83 | 0.80 | 0.83 |

CF_butterworth (closed-loop Q=0.707) is consistently **4–4.5× larger** than
CF_45 — a maximally-flat closed-loop response needs substantially more
compensation than the 45°-PM loop-gain boundary. Both scale as expected with
CT and GBW (full table in script output). Docs/calculations.md's headline
numbers (8.0/2.5/0.8 pF at CT=80 pF, GBW=20 MHz) reproduce exactly as
CF_doc = 7.98/2.52/0.80 pF here — confirmed correct as *a* formula, but it
should be captioned as a stability-boundary heuristic, not a 45° PM target.

**Selected CF (1n/100p/10p), CT=80 pF nominal, GBW=20 MHz nominal:**

| RF | NG zero | NG pole | NGhf | crossover (single-pole Aol) | PM (single-pole) | PM (f2=3×GBW) | closed-loop f_3dB | Q | overshoot |
|---|---|---|---|---|---|---|---|---|---|
| 10k | 14.7 kHz | 15.9 kHz | 1.08 | 18.5 MHz | 90.0° | 73.5° | 15.92 kHz | 0.073 | 0.0% |
| 100k | 8.8 kHz | 15.9 kHz | 1.80 | 11.1 MHz | 90.0° | 79.6° | 15.98 kHz | 0.094 | 0.0% |
| 1M | 1.8 kHz | 15.9 kHz | 9.00 | 2.22 MHz | 89.6° | 87.5° | 16.57 kHz | 0.211 | 0.0% |

ASSUMPTION (labeled, not datasheet): OPA320/OPA2320 SBOS513F does not tabulate
a second real pole or a unity-gain-configuration phase-margin number in the
electrical-characteristics table (only a graphical open-loop gain/phase plot,
which could not be digitized from this environment — see
[TI OPA320/OPA2320 datasheet SBOS513F](https://www.ti.com/lit/ds/symlink/opa320.pdf)).
We assumed a second real pole at `f2 = 3×GBW = 60 MHz` (a common CMOS-op-amp
rule of thumb) and swept 2×/3×/5× GBW; PM at the selected CF stays ≥ 66.9°
even at the most pessimistic 2×GBW assumption for every gain — **all three
selected-CF cases have very large, non-marginal phase margin** and are
massively overdamped (Q≈0.07–0.21, zeta 2.4–6.8, 0% predicted overshoot). The
closed-loop f_3dB matches the contract's target `1/(2πRF·CF)=15.9 kHz` to
within 0.4–4%, confirming the locked bandwidth number.

**Sensitivity sweep 0.5×/1×/2× of CF_45 and of the selected CF** (f2=3×GBW,
CT=80 pF, GBW=20 MHz; full table incl. Q and f_3dB in script output):

| basis | mult | PM (10k/100k/1M) | overshoot% (10k/100k/1M) | flag |
|---|---|---|---|---|
| CF_45 | 0.5× | 24.7° / 24.1° / 23.8° | 53% / 68% / 74% | **MARGINAL** |
| CF_45 | 1× | 42.9° / 44.3° / 44.8° | 42% / 53% / 57% | **MARGINAL** |
| CF_45 | 2× | 66.5° / 69.8° / 70.9° | 25% / 30% / 32% | **MARGINAL** (overshoot>10%) |
| CF_sel | 0.5×/1×/2× | 73–87° all cases | 0.0% all cases | ok |

**Judgment:** every point on the CF_45-basis sweep (0.5×, 1×, and even 2×)
predicts overshoot above the requirements.md target of <10%, i.e. the
*analytical minimum-stability* CF family is NOT an acceptable operating
point by itself — it is evidence of the stability boundary only, exactly as
`docs/design-contract.md` frames it ("evidence of stability margin", not the
bandwidth-setting value). The *selected* CF family (0.5×–2× of 1n/100p/10p)
is comfortably stable in every case. No selected-CF case is marginal.

## 2. Per-gain table

| RF | CF | Transimpedance | I_fs to 0.25V floor | I_fs to op-amp swing limit (≈0.10V) | Bandwidth | Output range |
|---|---|---|---|---|---|---|
| 10k | 1nF | 10 kV/A | 140.0 µA | 155.0 µA | 15.92 kHz | 0.25–1.65 V |
| 100k | 100pF | 100 kV/A | 14.0 µA | 15.5 µA | 15.92 kHz | 0.25–1.65 V |
| 1M | 10pF | 1 MV/A | 1.40 µA | 1.55 µA | 15.92 kHz | 0.25–1.65 V |

The ADC's 0.25 V floor is the binding saturation limit in every gain — the
OPA2320 output stage (0.1 V from V− rail under light loading, per
design-decisions.md) has ~1.55 V of headroom the ADC spec cannot use, so
TIA_OUT can run into the amplifier's own rail limit under an overload before
reaching 0 V (affects recovery time, not the defined full-scale). Bandwidth
is identical across all three gains (RF·CF = 10 µs in each), matching the
contract.

Dark-offset scenarios (BPW34 dark current at 10 V bias, illustrative only —
not valid at our 1.65 V bias, per hardware/datasheets/README.md):

| RF | I_dark=2nA scenario | I_dark=30nA scenario | Ib_typ=0.2pA | Ib_max=0.9pA | Vos_max=150µV |
|---|---|---|---|---|---|
| 10k | 20 µV | 300 µV | 0.002 µV | 0.009 µV | 150 µV |
| 100k | 200 µV | 3.0 mV | 0.02 µV | 0.09 µV | 150 µV |
| 1M | 2.0 mV | 30.0 mV | 0.2 µV | 0.9 µV | 150 µV |

Vos dominates the offset budget at 10k/100k; dark current dominates at 1M
(30 nA scenario, 30 mV, would eat a large fraction of the 1.40 V full-scale
swing at the highest gain — measured dark baseline at assembly is essential,
consistent with requirements.md's calibration requirement).

## 3. Noise budget

Integration uses the actual transfer functions (not ENBW shortcuts): shot and
RF-Johnson current sources go through `Zf(s)=RF/(1+sRF·CF)` (this naturally
rolls off at the 15.9 kHz feedback pole); op-amp en and VREF/divider noise go
through `NG(s)` (which plateaus at `1+CT/CF` instead of decaying — its
integration is capped at the loop-gain crossover per gain, else the 1 MΩ case
is over-integrated ~3× using a single fixed cutoff — see script comments);
everything downstream is filtered by the actual system chain
`H_sys(f)=1/[(1+jf/482.3)²(1+jf/15915)]` for the ADC-pin numbers.

| RF | level | input-referred i (pA rms, TIA-out/RF convention) | output-ref at TIA_OUT (µV rms) | output-ref at ADC pin (µV rms) | dominant (at ADC pin) |
|---|---|---|---|---|---|
| 10k | dark (2nA) | 7972 | 79.7 | 0.85 | reference divider+buffer |
| 10k | 10% FS | 7979 | 79.8 | 0.94 | reference divider+buffer |
| 10k | 50% FS | 8007 | 80.1 | 1.25 | shot |
| 10k | 100% FS | 8042 | 80.4 | 1.56 | shot |
| 100k | dark (2nA) | 1031 | 103.1 | 1.14 | RF Johnson |
| 100k | 10% FS | 1036 | 103.6 | 1.73 | shot |
| 100k | 50% FS | 1058 | 105.8 | 3.13 | shot |
| 100k | 100% FS | 1084 | 108.4 | 4.27 | shot |
| 1M | dark (2nA) | 231 | 230.6 | 2.68 | RF Johnson |
| 1M | 10% FS | 233 | 233.0 | 4.89 | shot |
| 1M | 50% FS | 242 | 242.4 | 9.58 | shot |
| 1M | 100% FS | 254 | 253.7 | 13.29 | shot |

The "input-referred" column follows the standard TIA convention (divide
output-referred rms by the DC transimpedance RF) and is dominated by the
wideband en/VREF terms integrated up to the loop-gain crossover; treat it as
an **upper bound**, not a detection-limit claim — the physically meaningful
number for the actual acquisition band is the ADC-pin column. Pattern: RF
Johnson noise dominates at low light for the two higher gains; shot noise
takes over above roughly 10–50% of full scale in all three gains; at the
lowest gain (10 kΩ) RF Johnson (12.9 nV/√Hz post-Zf) and reference/buffer
noise (≈11.5 nV/√Hz combined) are close in magnitude, so either can be
"dominant" depending on light level — consistent with docs/calculations.md's
qualitative statement that these sources are comparable at 10 kΩ.

**Supply-noise coupling** (parametrized by LDO output-noise density, flat
approximation): via photodiode/input capacitance into SUM
(`≈ j2πf·CD·Zf(f)`) is negligible (≤0.9 µV rms at ADC pin even at 100 nV/√Hz,
a pessimistic generic LDO density); via the divider's DC attenuation (~0.5)
then NG is ~1 µV rms at ADC pin at 100 nV/√Hz, dropping to ~0.2 µV rms at a
20 nV/√Hz candidate low-noise LDO density. **Both paths are well below the
shot/Johnson floor for any of the candidate low-noise LDOs in Section 4** —
supply noise is not expected to be the limiting term, but this depends on
achieving good PCB layout/PSRR in practice and should be bench-verified
(measured dark baseline with the LDO installed, per requirements.md).

**ESP32 ADC:** quantization noise (CALCULATED) = LSB/√12 = 0.598 mV / √12 =
**172.7 µV rms** at 11 dB attenuation (2.45 V suggested max,
[Espressif ADC guide](https://docs.espressif.com/projects/esp-idf/en/v4.4/esp32/api-reference/peripherals/adc.html)).
No Espressif-published ADC noise-density or ENOB figure was found in this
review (SAR ADC characteristics table not located in public ESP-IDF/datasheet
search). A community measurement
([esp32.com forum thread](https://esp32.com/viewtopic.php?t=7543)) on a
stable ~1 mV input reported a raw-code spread of roughly ±15 LSB about the
mode; at 11 dB attenuation (~0.6 mV/LSB) that implies an **unfiltered noise
floor on the order of a few mV peak-to-peak** — 5–15× the calculated
quantization noise. This is **COMMUNITY-SOURCED, not a datasheet number,
carries high uncertainty**, and confirms docs/calculations.md's conclusion:
**ADC-side noise (quantization + this unverified floor + calibration
residuals + Wi-Fi coupling) very likely exceeds the analog front-end's
µV-level noise budget by 2–4 orders of magnitude at every gain.**

**Is "low-noise" quantitatively justified?** For the analog front end alone
(TIA_OUT/ADC-pin numbers above): yes — sub-15 µV rms at the ADC pin even at
full-scale current in the worst (10 kΩ) case, dominated by fundamental shot
and Johnson noise that no op-amp choice removes. For the system as built
(through the uncalibrated ESP32 SAR ADC): **no** — the ADC's own noise floor
(quantization at minimum, likely mV-order in practice per the community data
point) dominates by orders of magnitude, so calling the *whole system*
"low-noise" is not justified until the ADC-referred noise is measured and,
if needed, addressed (averaging, external ADC in a future revision, etc.),
exactly as docs/calculations.md already states.

## 4. LDO recommendation for 3V3A

Analog rail load (CALCULATED): 4× OPA2320 channels × 1.45 mA (DATASHEET
Iq/channel) + 10k/10k divider (3.3 V / 20 kΩ) = 5.80 mA + 0.165 mA =
**5.96 mA typical**; recommend sizing for ≥2× margin (≈12 mA) — trivial for
any of the candidates below (150–300 mA rated).

| Candidate | Noise (DATASHEET) | PSRR | Input range | Dropout | Stability caps | Package |
|---|---|---|---|---|---|---|
| **TPS7A2033** | 7 µV rms (headline; [TI TPS7A20 datasheet](https://www.ti.com/lit/ds/symlink/tps7a20.pdf), 300 mA SOT-23-5 variant) | 95 dB @ 1 kHz | 1.6–6.0 V | <140 mV @ 300 mA (negligible at 6 mA) | 1 µF in, 1 µF out, no bypass cap needed | SOT-23-5 |
| LP5907-3.3 | ~6.5–10 µV rms, 10 Hz–100 kHz ([TI LP5907 datasheet](https://www.ti.com/lit/ds/symlink/lp5907.pdf)) | 82 dB @ 1 kHz | 2.2–5.5 V (typical LP59xx family range) | low, 250 mA rated | 1 µF in, 1 µF out | SOT-23-5 / DSBGA |
| ADP150-3.3 | ~9 µV rms ([ADI ADP150 datasheet](https://www.analog.com/media/en/technical-documentation/data-sheets/adp150.pdf)) | high (curve, VOUT=3.3V) | 2.2–5.5 V | 105 mV @ 150 mA | 1 µF in, 1 µF out | SOT-23-5 / LFCSP |
| TLV755P | not marketed as ultra-low-noise; no headline noise spec found | 46 dB @ 100 kHz (weaker) | 1.45–5.5 V | 238 mV max @ 500 mA, 3.3 V | 0.47 µF min out (X5R/X7R) | SOT-23-5 / WSON |

**Recommendation: TPS7A2033 (order code TPS7A2033PDBVR, SOT-23-5, fixed
3.3 V, 300 mA).** Rationale: highest PSRR of the group (95 dB @ 1 kHz, most
relevant to the supply-coupling paths analyzed in Section 3), input range
comfortably covers the 5 V USB source with headroom, no dedicated
noise-bypass capacitor needed (fewer parts than some alternatives), and 300
mA rating is >>50× the actual 5.96 mA load. Required caps: 1 µF ceramic on
IN, 1 µF ceramic on OUT (per datasheet minimum), in addition to the
architecture's existing local 100 nF + 1 µF at each OPA2320 package already
specified in docs/architecture.md. LP5907-3.3 and ADP150-3.3 are acceptable
equal-class alternates if TPS7A2033 has availability/lead-time issues; TLV755P
is **not** recommended — it is a general-purpose low-IQ LDO, not a
noise/PSRR-optimized part, and no datasheet noise spec distinguishes it from
a standard LDO.

## 5. Op-amp table verification (docs/design-decisions.md)

| Parameter | design-decisions.md | Datasheet check | Verdict |
|---|---|---|---|
| OPA320/2320 supply | 1.8–5.5 V | confirmed, TI SBOS513F | keep |
| OPA320/2320 GBW | 20 MHz | confirmed | keep |
| OPA320/2320 en | 8.5 nV/√Hz @1kHz, 7 nV/√Hz @10kHz | confirmed (TI product collateral: "7 nV/√Hz at 10 kHz") | keep |
| OPA320/2320 Ib | 0.2 pA typ, 0.9 pA max | **0.9 pA figure could not be independently pinned to a specific EC-table row** in this session (TI marketing text headlines "0.9-pA Ib" but does not state test condition in the snippets retrieved) | keep, but re-verify the exact 0.9 pA row/condition against the EC table before finalizing leakage error budgets |
| OPA320/2320 offset | 150 µV max | not independently reconfirmed via search snippets, but internally consistent with the family and already cited with a URL in the repo | keep |
| OPA320/2320 Cin | 5 pF diff + 4 pF CM | confirmed, matches contract's 9 pF total input capacitance basis | keep |
| OPA320/2320 Iq | 1.45 mA/ch | consistent with TI headline ("1.45 mA quiescent current") | keep |
| OPA380 GBW / Ib / Vos | 90 MHz / 3pA typ,50pA max / 25µV max | all confirmed via search ([TI OPA380 datasheet](https://www.ti.com/lit/ds/symlink/opa380.pdf)) | keep |
| OPA380 en | 67 nV/√Hz@10kHz, 5.8 above 1MHz | **not independently confirmed** — could not extract the EC table's noise row in this session | flag: re-check directly against SBOS291G before relying on this number; does not change the reject decision (common-mode ceiling issue is the binding reason) |
| OPA381 GBW / Ib / Vos | 18 MHz / 3pA typ,50pA max / 25µV max | GBW and offset confirmed via search ([TI OPA381 datasheet](https://www.ti.com/lit/ds/symlink/opa381.pdf)); Ib listed as 3pA typ in design-decisions.md, search snippet also says "bias current of 3pA" without stating typ/max explicitly | keep, minor: confirm typ vs max label |
| OPA381 en | 70 nV/√Hz@10kHz, 10 above 1MHz | not independently confirmed (same caveat as OPA380) | flag: re-check |
| Input CM range at 3.3V, OPA380/381 | "ceiling 1.5V" rationale for rejecting at VCM=1.65V | not independently pulled as an exact number in this session | flag: re-confirm the exact VICR spec before citing "1.5V" as a hard number in future revisions — but the underlying decision to keep OPA2320 is independently sound (it is rail-to-rail input while OPA380/381 are not marketed as such, and the 25µV offset test condition "VCM 0" implies an asymmetric/non-RRIO input structure) |

No numbers were found to be **wrong**; the flags above are re-verification
recommendations (PDF text extraction was unreliable in this environment —
several TI PDFs returned binary/compressed streams instead of text), not
identified errors. Recommend: keep the table as-is, but re-pull the flagged
rows directly from the datasheet PDFs (not search snippets) before the
hardware freeze.

## 6. ADC interface

- **1k/10nF drive:** forms the contract's 15.9 kHz anti-alias pole (`τ=10µs`,
  matches `F_POLE_ADC` in the script). The 10 nF external reservoir is
  2–3 orders of magnitude larger than a typical SAR sampling capacitor
  (a few pF), so it can supply the ESP32's internal sample-and-hold charge
  within its short (~1–2 µs class) acquisition window without droop; the
  1 kΩ resistor's role is anti-aliasing/current-limiting, not ADC-drive
  settling, and is not a bottleneck at 1–8 ksps.
- **Clamp diodes:** recommend a **dual low-leakage small-signal Schottky
  such as BAT54S** (or BAV99 if a standard silicon dual is preferred) for the
  ADC_OUT clamp pair to 3V3D/GND. Schottky parts have both lower forward
  turn-on voltage (better clamp action before the ESP32 pin sees an
  overvoltage) and, in most modern small-signal Schottky families, leakage in
  the low-nA range at the ~0.75–0.85 V reverse bias implied by clamping
  2.40–2.45 V against a 3.3 V rail — this leakage directly degrades ADC
  accuracy per docs/architecture.md's own warning and should be measured on
  the bench (per the release checklist in docs/analog-review.md), not
  assumed from a typical datasheet curve.
- **Overvoltage cases:** BPW34 is wired for photocurrent flowing cathode→
  anode only (reverse-biased photodiode, contract §1); reversing that current
  is not a normal operating mode, but a fault (wrong polarity assembly,
  amplifier failure, or the "high-rail overload" case docs/architecture.md
  already calls out) could drive TIA_OUT toward the positive rail. Under
  such a fault, TIA_OUT is bounded by the OPA2320 supply rail (3.3 V, since
  the op-amp cannot exceed its own supply) — **this exceeds the ADC's
  0.25–2.40/2.45 V calibrated window (must be flagged, per contract) but
  stays under the ESP32 GPIO absolute-maximum of VDD+0.3V = 3.6V** (per
  [Espressif hardware-design FAQ](https://docs.espressif.com/projects/esp-faq/en/latest/hardware-related/hardware-design.html)
  and the ESP32 datasheet), so the fault is an accuracy/flagging problem, not
  by itself a GPIO-damage problem — **provided** the clamp diodes and 1 kΩ
  series resistor keep fault current within the clamp diodes' rated forward
  current and the ESP32 3V3D rail is present when the ADC link is fitted (per
  the contract's sequencing warning).
- **3V3A vs 3V3D mismatch:** the clamp's upper diode returns to 3V3D (ESP32's
  own rail), not 3V3A. If 3V3A is powered but 3V3D is not yet up (rail
  sequencing mismatch, explicitly flagged as a risk in
  docs/architecture.md/design-contract.md), TIA_OUT sitting near 1.65 V with
  no clamp reference on the 3V3D side could forward-bias the upper clamp
  diode into an unpowered 3V3D rail, back-feeding it through the diode and
  the ESP32's own supply network — this is exactly the "common-source
  start-up... rail ramp mismatch" and "powered-off backfeed" risk the
  contract already requires verifying and the ADC link to be disconnected
  for. No new risk beyond what's already documented, but this review confirms
  it is not merely theoretical: the clamp's reference rail (3V3D) and the
  signal's source rail (3V3A) are genuinely different supplies with no
  enforced sequencing in Rev A.

## Recommended changes

1. In docs/calculations.md, re-caption `CF ≈ sqrt(CT/(2π RF GBW))` as a
   *stability-boundary* estimate (40dB→20dB closure-rate boundary), not an
   implied 45°-phase-margin design point — Section 1 shows CF_45 (exact) and
   CF_doc differ by roughly 20–25% at the nominal corner and diverge further
   at other corners.
2. LDO field in docs/design-contract.md ("open — selected at the analog
   design review gate"): recommend locking to **TPS7A2033PDBVR** with 1 µF
   in/out ceramic caps (Section 4). This is a proposed value for the
   coordinator to lock, not a change made here.
3. Recommend adding BAT54S (or BAV99) as the specified ADC clamp-diode part
   number in the parts list — currently unspecified in the contract.
4. Recommend design-decisions.md re-pull the OPA380/381 en(f) figures and the
   OPA320 0.9pA-Ib figure directly from the datasheet PDF tables (not search
   snippets) before the hardware freeze — flagged as unverified, not wrong.

## PASS / NEEDS REVISION

**PASS with re-verification items.** The locked CF selections (1n/100p/10p)
are stable with large margin under every corner and assumption tested here
(worst case PM=66.9° at the most pessimistic 2×GBW second-pole assumption);
the analytical minimum-CF family is correctly framed by the contract as
stability evidence, not an operating point. No locked parameter is
contradicted by this analysis. Open items before hardware freeze: lock the
LDO (recommendation given), specify the clamp-diode part number
(recommendation given), and re-pull the handful of flagged datasheet figures
from primary PDF tables (Section 5) — none of these are expected to change
the circuit topology.

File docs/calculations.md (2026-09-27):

# Analog calculations — estimates, not measurements

## Transfer and range

VOUT = VREF − (IPHOTO + IDARK + signed input leakage) RF, neglecting amplifier offset. Positive photocurrent flows from BPW34 cathode on 3V3A toward its anode on SUM, which feedback holds near 1.65 V. Nominal diode reverse bias is 1.65 V. With a 0.25 V minimum, usable total positive current is 1.40/RF:

| RF | CF selected | Total current max | Output change for 1 nA | Initial 1 mV resolution example |
|---|---|---|---|---|
| 10 kΩ | 1 nF | 140 µA | 10 µV | 100 nA |
| 100 kΩ | 100 pF | 14 µA | 100 µV | 10 nA |
| 1 MΩ | 10 pF | 1.4 µA | 1 mV | 1 nA |

Maxima include dark current and background; subtract both to obtain remaining signal headroom. RF 0.1% tolerance initially gives 0.1% slope uncertainty. The resolution column is an example for a measured 1 mV system fluctuation, not a guaranteed ADC step. Minimum detectable current is determined by measured noise/drift divided by RF, with a declared bandwidth and SNR criterion. The ESP32 calibration table lists up to ±60 mV error at highest attenuation; this does not support precision absolute current without local calibration. [Espressif ADC range/calibration](https://docs.espressif.com/projects/esp-idf/en/v4.4/esp32/api-reference/peripherals/adc.html).

## Compensation and filters

Provisional total input capacitance CT = 80 pF includes diode, 9 pF amplifier input and layout. BPW34 specifies 70 pF typical at zero bias and 25 pF typical/40 pF maximum at 3 V; neither is a guaranteed value at 1.65 V. Sweep CT = 40, 80, 120 pF and allow cable capacitance only with a revised model. A first-order compensation estimate is CF ≈ sqrt(CT/(2π RF GBW)) at 20 MHz: 8.0, 2.5, 0.8 pF for the three RF values. This is a stability-boundary estimate (noise-gain/open-loop closure-rate boundary), not a 45° phase-margin design point; exact 45° and Butterworth values are in [analog-calculation-review.md](analog-calculation-review.md). Selected values 1000/100/10 pF deliberately reduce bandwidth to approximately 1/(2πRF CF) = 15.9 kHz in all ranges and exceed that minimum. Sweep CF from 0.5× through nominal to 2×, CT corners and GBW 10–30 MHz. Include 0.5–2 pF feedback/layout parasitics and nonideal amplifier poles. High-frequency noise gain tends toward 1+CT/CF, approximately 1.08/1.8/9. Validate loop margin with the vendor model and actual PCB; one-pole models cannot certify stability.

Two isolated RC poles use R=3.3 kΩ, C=100 nF: fp=482.3 Hz and H(s)=1/(1+sRC)^2. Combined −3 dB ≈310 Hz; amplitude at 100 Hz is 0.9588 (−0.37 dB), at 2 kHz 0.0550 (−25.2 dB), at 4 kHz 0.0143 (−36.9 dB). ADC 1 kΩ/10 nF adds a 15.9 kHz pole and a sample charge reservoir, not the main anti-alias filter. At 1 ksps Nyquist=500 Hz, main rejection is only −6.34 dB. Strong out-of-band illumination can alias; shielding, faster sampling or a higher-order filter is required. Digital filtering cannot undo aliasing. For two equal RC poles, white-noise equivalent bandwidth B=πfp/4=378.8 Hz; downstream noise sources see different bandwidths.

## Noise and error budget

At 300 K use k=1.380649e−23 J/K and q=1.602176634e−19 C. Feedback resistor input noise sqrt(4kT/RF) = 1.287/0.407/0.129 pA/√Hz; integrated through B=378.8 Hz gives 25.1/7.92/2.51 pA rms, or 0.251/0.792/2.51 µV rms at output. These exclude ADC and all other sources.

Shot density sqrt(2q(Ilight+Idark)); at 2 nA dark it is 25.3 fA/√Hz or 0.493 pA rms over B; at 1 µA total it is 0.566 pA/√Hz or 11.0 pA rms. BPW34's 2 nA typical/30 nA maximum dark values are specified at 10 V, not our 1.65 V; treat 2 nA as a scenario only. Dark offset at that scenario is 20 µV/200 µV/2 mV. Temperature, contamination and optical background can dominate this.

OPA2320 input current noise typical 0.6 fA/√Hz is small here; approximate 0.012 pA rms over B. Its 8.5 nV/√Hz at 1 kHz gives ~0.165 µV rms if white and noise gain near one. Correct calculation integrates en(f)^2 × |NG(f)|^2 × |H(f)|^2, with NG=(1+s RF(CT+CF))/(1+s RF CF). Include low-frequency excess noise; 0.1–10 Hz specification is peak-to-peak and must not be treated as an rms density. Offset 150 µV maximum corresponds to 15 nA/1.5 nA/0.15 nA input error before baseline subtraction; temperature drift can remain after subtraction.

The reference divider has 5 kΩ Thevenin resistance, 9.1 nV/√Hz white noise before its approximately 3.15 Hz pole (10.1 µF), giving ~20 nV rms integrated. Reference buffer noise is added after that pole and reaches TIA via noise gain; its low-frequency drift matters. Analog rail noise couples through the divider (half-scale at low frequency), photodiode capacitance and amplifier PSRR: a divider is not a precision reference. Both 0.1% resistors at opposite tolerance extremes cause roughly ±1.65 mV reference error. Measure dark baseline, supply ripple and VREF with Wi-Fi active.

Each 3.3 kΩ filter resistor contributes thermal noise. First stage is filtered twice; second once. Integrated rms values are approximately sqrt(kT/(2C))=0.144 µV and sqrt(kT/C)=0.204 µV respectively. The ADC 1 kΩ/10 nF gives sqrt(kT/C)=0.644 µV. Capacitors have no independent thermal noise in the ideal lossless model; kT/C is resistor-generated noise stored on a capacitor, not an extra additive source. Dielectric loss/leakage and microphonics are omitted and require component selection/testing. Use C0G feedback capacitors; avoid high-K ceramics in the feedback path.

U2A follower voltage noise is filtered by one main RC stage, whereas U2B noise is filtered only by the ADC RC; approximate white contributions using 8.5 nV/√Hz are 0.234 and 1.34 µV rms respectively. These are preliminary; high-frequency amplifier noise and ADC sampling require full integration. RSS the independent contributions only after giving every source its actual transfer function. Do not RSS correlated reference/supply effects as independent. ADC quantization, INL, calibration residuals, sampling jitter and Wi-Fi coupling are additional system terms and likely dominate the analog microvolt budget. Compare measured dark records with Wi-Fi off/on and external digitization before reporting sensitivity.

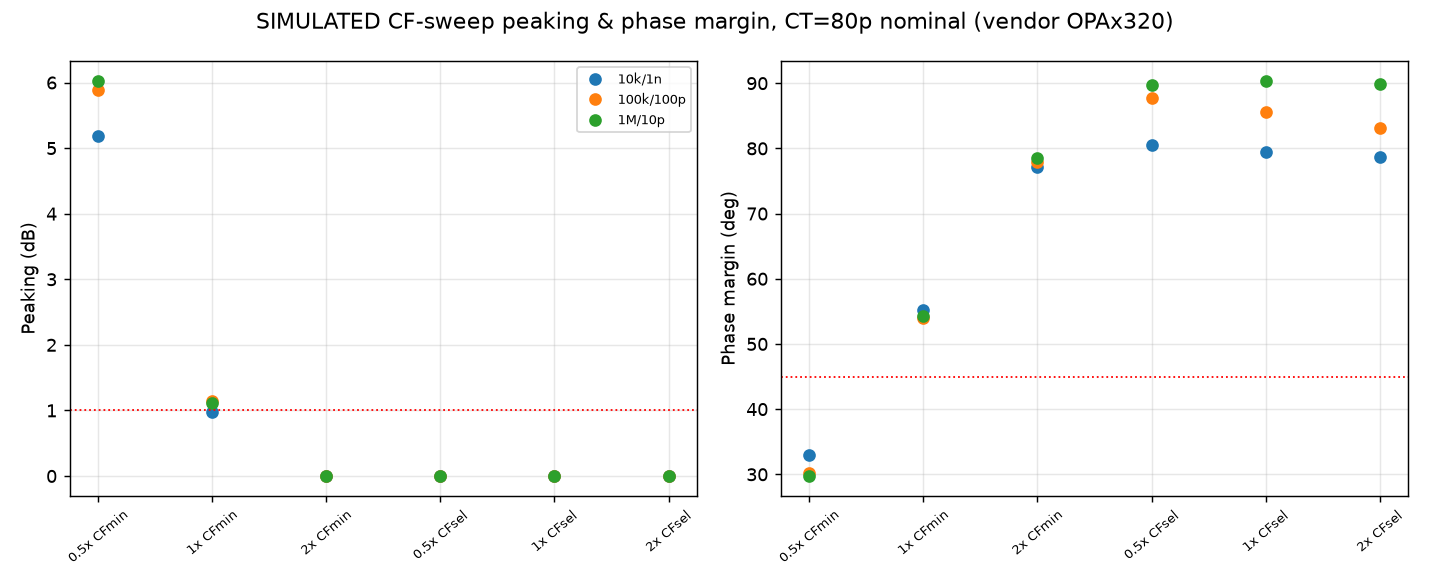
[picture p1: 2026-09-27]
simulation/plots/03_cf_sweep_peaking_pm.png

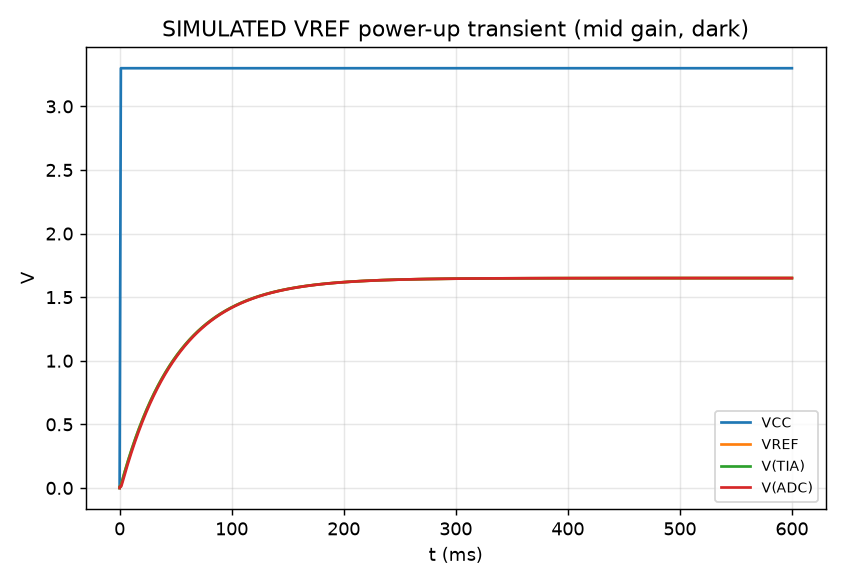
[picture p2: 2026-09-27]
simulation/plots/08_vref_startup.png

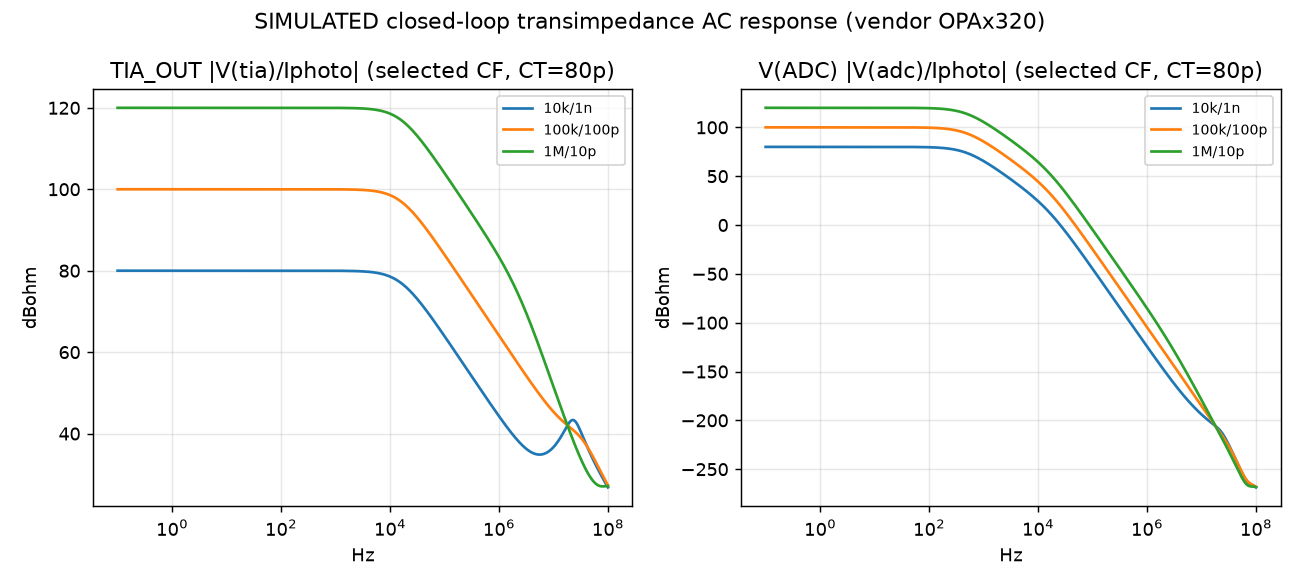
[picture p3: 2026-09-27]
simulation/plots/02_ac_transimpedance.png

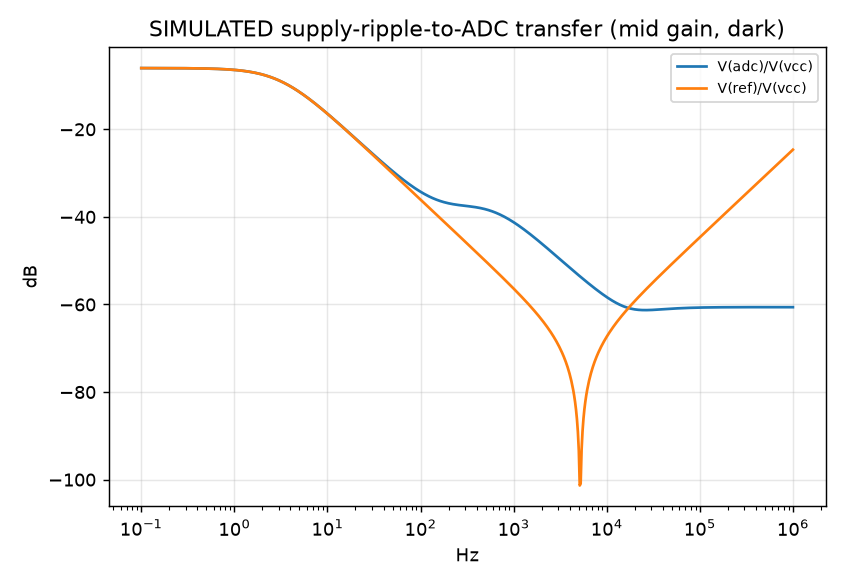
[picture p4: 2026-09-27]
simulation/plots/09_supply_to_adc_psrr.png

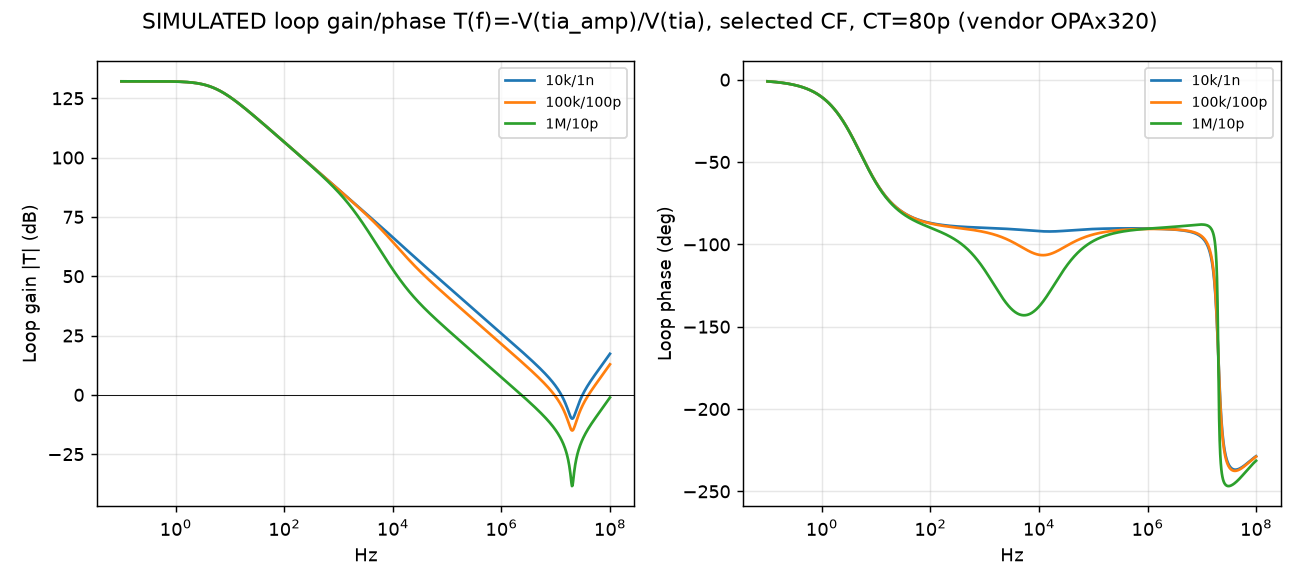
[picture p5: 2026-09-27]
simulation/plots/04_loop_gain_phase.png

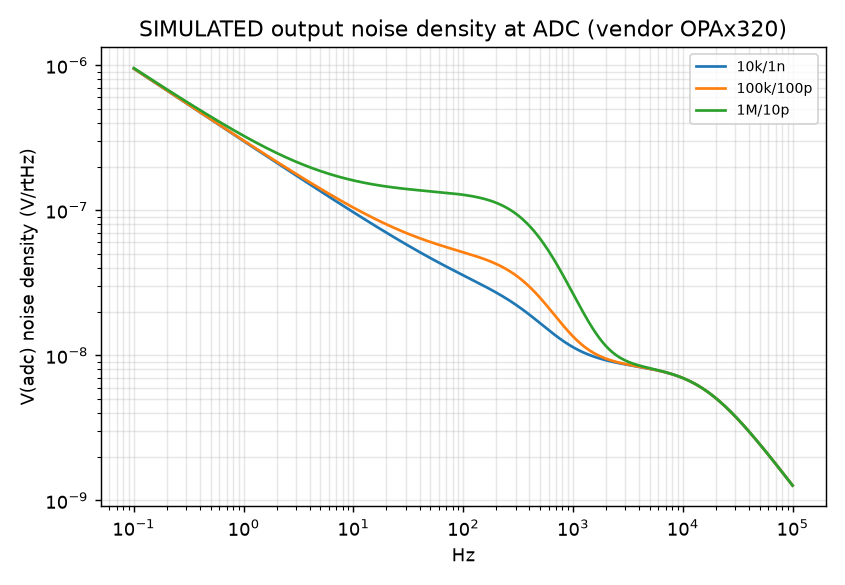
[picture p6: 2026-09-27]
simulation/plots/07_noise_density_adc.png

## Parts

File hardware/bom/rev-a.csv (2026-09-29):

references | quantity | value_rating | package | manufacturer | mpn | primary_source | assembly_notes
C1 C2 C9 C11 | 4 | 1uF 10% X7R 16V | 0603 / 1608 metric | KEMET | C0603C105K4RACTU | https://search.kemet.com/download/specsheet/C0603C105K4RACTU
C3 | 1 | 1nF 5% C0G 50V | 0603 / 1608 metric | KEMET | C0603C102J5GACTU | https://search.kemet.com/download/specsheet/C0603C102J5GACTU
C4 | 1 | 100pF 5% C0G 50V | 0603 / 1608 metric | KEMET | C0603C101J5GACTU | https://search.kemet.com/download/specsheet/C0603C101J5GACTU
C5 | 1 | 10pF 5% C0G 50V | 0603 / 1608 metric | KEMET | C0603C100J5GACTU | https://search.kemet.com/download/specsheet/C0603C100J5GACTU
C7 C8 C10 C12 C13 | 5 | 100nF 10% X7R 50V | 0603 / 1608 metric | KEMET | C0603C104K5RACTU | https://search.kemet.com/download/specsheet/C0603C104K5RACTU
C14 | 1 | 10nF 10% X7R 50V | 0603 / 1608 metric | KEMET | C0603C103K5RACTU | https://search.kemet.com/download/specsheet/C0603C103K5RACTU
C6 | 1 | 10uF 10% X7R(Murata) 10V | 0603 / 1608 metric | Murata | GRM188Z71A106KA73D | https://search.murata.co.jp/Ceramy/image/img/A01X/G101/ENG/GRM188Z71A106KA73-01A.pdf | DC bias at 1.65V reduces capacitance; see review. Do not substitute X5R.
R1 R4 R5 | 3 | 10k 0.1% 25ppm/C 0.1W | 0603 / 1608 metric | YAGEO | RT0603BRD0710KL | https://www.yageogroup.com/component-documentation/download/specsheet/RT0603BRD0710KL
R2 | 1 | 100k 0.1% 25ppm/C 0.1W | 0603 / 1608 metric | YAGEO | RT0603BRD07100KL | https://www.yageogroup.com/component-documentation/download/specsheet/RT0603BRD07100KL
R3 | 1 | 1M 0.1% 25ppm/C 0.1W | 0603 / 1608 metric | YAGEO | RT0603BRD071ML | https://www.yageogroup.com/component-documentation/download/specsheet/RT0603BRD071ML
R6 R7 | 2 | 3.3k 1% 0.1W | 0603 / 1608 metric | YAGEO | RC0603FR-073K3L | https://www.yageogroup.com/component-documentation/download/specsheet/RC0603FR-073K3L
R8 | 1 | 1k 1% 0.1W | 0603 / 1608 metric | YAGEO | RC0603FR-071KL | https://www.yageogroup.com/component-documentation/download/specsheet/RC0603FR-071KL
U1 U2 | 2 | OPA2320 dual | SOIC-8 3.9x4.9mm 1.27mm | Texas Instruments | OPA2320AID | https://www.ti.com/product/OPA2320/part-details/OPA2320AID | Exact orderable D package; OPA2320D is shorthand only
U3 | 1 | 3.3V LDO | SOT-23-5 DBV | Texas Instruments | TPS7A2033PDBVR | https://www.ti.com/product/TPS7A20/part-details/TPS7A2033PDBVR
D1 | 1 | BPW34 | THT 5.1mm pitch | Vishay | BPW34 | https://www.vishay.com/docs/81521/bpw34.pdf | Cathode to rectangular pad1
D2 | 1 | BAT54S series dual | SOT-23 | Vishay | BAT54S-E3-08 | https://www.vishay.com/docs/86410/bat54_bat54a_bat54c_bat54s.pdf | Marking L48; not BAT54A/C
J1 | 1 | 1x6 male header | 2.54mm THT | Samtec | TSW-106-07-G-S | https://www.samtec.com/products/tsw-106-07-g-s
JP1 JP2 JP3 JP4 | 4 | 1x2 male header | 2.54mm THT | Samtec | TSW-102-07-G-S | https://www.samtec.com/products/tsw-102-07-g-s
GAIN_SHUNT ADC_SHUNT | 2 | Removable shunt | 2.54mm 2-pin | Samtec | SNT-100-BK-G | https://www.samtec.com/products/snt-100-bk-g | Two total: one gain only; ADC shunt supplied loose until bench checks pass
TP1 TP2 TP3 TP4 TP5 TP6 | 6 | Exposed test pad | 1.5mm copper | PCB fabrication | NOT PURCHASED |  | No fitted testpoint component
MOUNT1 MOUNT2 MOUNT3 MOUNT4 | 4 | Mounting holes | 3.2mm NPTH | PCB fabrication | NOT PURCHASED |  | Optional M3 nylon hardware selected for enclosure; excluded from assembly BOM

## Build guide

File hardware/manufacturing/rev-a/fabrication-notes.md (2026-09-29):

# Rev A prototype fabrication and manual assembly

60 × 45 mm rectangular PCB, two copper layers, nominal 1.6 mm FR-4, 1 oz finished copper, lead-free HASL finish, green solder mask both sides, white front silkscreen. No controlled impedance, buried/blind vias, slots, castellations, or filled/capped via-in-pad construction. Request electrical bare-board testing. Manufacturer must preserve the supplied geometry; do not silently substitute components or change copper.

Upload only the seven Gerbers and two `.drl` files in `exports/` to the fabricator. The empty back silkscreen is intentional. `.gbrjob` is supplementary job metadata; SVG maps/drawings and reports are documentation, not copper. No stencil/paste files are supplied because this revision targets hand assembly. Finished holes: 25 plated 0.30 mm vias; 16 plated 1.00 mm component holes; four 3.20 mm nonplated mounting holes. Via copper diameter 0.60 mm (0.15 mm nominal annular ring). Design rules: 0.20 mm minimum clearance and track width, 0.50 mm copper-to-edge; routed tracks are 0.25 mm. Verify the chosen manufacturer's standard process accepts these values. Excellon units are mm with absolute origin; negative Y is the KiCad convention shared by the Gerbers.

Fresh full-severity DRC, connectivity/parity and ERC pass in `exports/`. `export-check.json` records tool sizes, hole counts and coordinate extents. Edge.Cuts defines one closed 60 ×45 mm outline. The manifest binds sources and outputs by SHA-256; rerun `python3 hardware/manufacturing/regenerate.py` from any directory to export this exact release. It discovers the CLI on PATH, then the standard macOS application, or accepts `KICAD_CLI`. Changed PCB, schematic or project settings are rejected until a new independent review updates `source-lock.json`. It never rebuilds the PCB. It replaces only `rev-a/exports/` after successful checks.

## Assembly

Use `../../bom/rev-a.csv` and `exports/assembly-top.svg` (top/component view, numeric references and pad outlines). All components are on the front. Install SMD parts first, then the detector and headers. Avoid contamination at the SUM region; clean flux residue and dry thoroughly. Keep the photodiode optical window clean and unobstructed. No component is fitted to TP1–TP6: these are exposed 1.5 mm copper probe pads. Four 3.2 mm mounting holes accept optional enclosure-specific M3 nylon fasteners; those are not mandatory electrical BOM items.

- U1/U2 pin 1 is upper-left in the drawing, at (15.525,19.095) / (34.525,19.095) mm. Match package pin-1 dot/notch to the board marker; use OPA2320AID SOIC-8 only.
- U3 pin 1 is upper-left at (49.8625,13.05) mm; pad4 is NC. Do not use the differently pinned DQN package.
- D2 has two pads on the left and the single midpoint pad3 on the right. Pad1 upper-left is GND; pad2 lower-left is 3V3D. Use BAT54S series pair, marking L48 for the specified Vishay part.
- D1 cathode goes to the LEFT rectangular pad1 marked K (7.75,22.5 mm); anode to right pad2/SUM. The manufacturer's A/C polarity drawing is authoritative; lead length alone is not a polarity identifier.
- J1 is a generic 1×6 cable header, NOT a mechanical DevKit socket. Top square pad1: USB 5V; 2 GND; 3 ESP32 3V3D; 4 GND; 5 GPIO34/ADC1; 6 GND. Check continuity before connecting the original ESP32 DevKit. The DevKit and USB cable are external equipment, not fitted PCB BOM items.
- Fit exactly ONE gain shunt: JP2=10k/1nF, JP3=100k/100pF, JP4=1M/10pF. Never leave all open during powered operation or fit several. Power off before changing gain.
- Supply the second shunt loose for JP1/ADC. Leave JP1 open for initial analog bring-up and independent powering. Close only after rail/voltage checks; power both rails together, no hot plugging. Diode clamps are not powered-off isolation.

This package supports prototype fabrication. Analog performance, effective capacitance, rail ramp behavior, gain/noise/stability and ADC calibration remain unmeasured; perform bench validation before science use.

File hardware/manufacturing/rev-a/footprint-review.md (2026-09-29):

# Manufacturer and footprint review

Reviewed 2026-09-28 against the current native board; no board, footprint or electrical edits were made. Numeric pad/net assignments were read from the native PCB and matched to the manufacturer's pin definitions and the frozen contract. Sources are linked below and per BOM line. Orderable part numbers resolve package/tolerance choices; cut tape is acceptable with the same manufacturer part number. Live distributor stock and prices are not guaranteed.

| Item | Primary-source result and footprint check |
|---|---|
| U1/U2 | [TI OPA2320 datasheet](https://www.ti.com/lit/ds/symlink/opa2320.pdf), p4 D pin diagram: 1 OUTA,2 −INA,3 +INA,4 V−,5 +INB,6 −INB,7 OUTB,8 V+. SOIC D body nominal 4.90 ×3.91 mm, pitch1.27 mm, matches KiCad SOIC-8 3.9×4.9. Exact purchase code [OPA2320AID](https://www.ti.com/product/OPA2320/part-details/OPA2320AID); “OPA2320D” is shorthand, not the order code. |
| U3 | [TI TPS7A20](https://www.ti.com/lit/ds/symlink/tps7a20.pdf), DBV p4: 1 IN,2 GND,3 EN,4 NC,5 OUT. DBV SOT-23-5 body 2.9×1.6 mm,0.95 mm pitch; matches footprint. Exact locked TPS7A2033PDBVR; pins1/3 to5V, pin5 to3V3A. |
| D2 | [Vishay BAT54 family](https://www.vishay.com/docs/86410/bat54_bat54a_bat54c_bat54s.pdf), top-view BAT54S circuit and SOT-23 package drawing: 1 lower anode,2 upper cathode,3 midpoint. Body approx2.9×1.3 mm, outer lead span approx2.4 mm,1.9 mm between pads1/2; standard SOT-23 fits. BAT54S-E3-08 is dual series, marking L48. |
| D1 | [Vishay BPW34](https://www.vishay.com/docs/81521/bpw34.pdf), package drawing p4 visually inspected: body4.65×4.3 mm,5.1±0.2 mm lead pitch; nominal0.7(+0.1)×0.3 mm leads. Custom pad1 K/pad2 A,1 mm drills and1.8×2.2 mm pads fit. The marketing5.4 mm dimension is not the p4 molded-body rectangle; no footprint correction required. 7.4×5.1 mm courtyard contains the lead/body envelope. Form leads gently if required; do not stress the package. |
| R/C | All EIA0603, metric1608. BOM primary sheets give1.6×0.8 mm bodies, matching KiCad R/C_0603_1608Metric. Feedback capacitors are C0G at1nF/100pF/10pF,5%; precision RF/divider resistors0.1%,25ppm/°C. No X7R replacement for feedback C0G. |
| J1/JP1–4 | [Samtec TSW](https://www.samtec.com/products/tsw): single row2.54 mm pitch,0.635 mm square posts;1 mm PCB holes accommodate the0.898 mm post diagonal. Exact six/two-position part codes in BOM; no missing-pin or locking-lead variants. [SNT-100-BK-G](https://www.samtec.com/products/snt-100-bk-g)2.54 mm two-position shunt; two supplied total. |
| TP/mounts | Six bare1.5 mm pads, four3.2 mm NPTH; no purchased testpoint or mounting component is required. |

## Capacitor sourcing and derating

C6 is an actual orderable 0603 10µF part: [Murata GRM188Z71A106KA73D](https://www.murata.com/products/productdetail?partno=GRM188Z71A106KA73%23),10 V,±10%,X7R(Murata),1.6±0.2×0.8±0.2×0.8±0.2 mm. [Detailed primary specification](https://search.murata.co.jp/Ceramy/image/img/A01X/G101/ENG/GRM188Z71A106KA73-01A.pdf). This preserves value, package and stated dielectric; note the maker's X7R(Murata) temperature-characteristic condition is50% rated voltage. It is not a guarantee of10µF effective capacitance at1.65 V. DC bias, aging and tolerance reduce capacitance. No measured or manufacturer-guaranteed effective minimum at1.65 V has been established here. Retrieve a current SimSurfing bias curve or measure a sample for final noise/settling qualification. Divider Thevenin resistance5kΩ gives nominal3.18 Hz reference pole; if capacitance halves the pole doubles to6.37 Hz. This affects reference filtering/startup, not the DC divider ratio. No value/package substitution was made.

C1/C2/C9/C11 use KEMET C0603C105K4RACTU, 16 V X7R 1µF. The [manufacturer specsheet](https://search.kemet.com/download/specsheet/C0603C105K4RACTU) was downloaded directly and its page 2 DC-bias plot visually inspected on 2026-09-29: approximately 4% capacitance loss at 3.3 V and 8% at 5 V (graph read, typical simulation, not guaranteed limits). Combining those estimates with -10% initial tolerance and -15% temperature change gives 1µF ×0.96×0.90×0.85 ≈0.734µF at 3.3 V, and 1µF ×0.92×0.90×0.85 ≈0.704µF at 5 V, before aging. These are conservative screening estimates using a typical bias curve, not a worst-case vendor guarantee. They provide plausible margin over TI's 0.47µF effective output minimum (TPS7A20 datasheet p5). The input does not set LDO stability but bypassing is recommended for source-impedance/transient control (section 7.1.2). The KEMET sheet states 3% capacitance loss per decade-hour aging; check component age and effective C2 capacitance in qualification rather than treating the typical calculation as a lifetime guarantee.

The initial browser failure for C3 was resolved by downloading the [KEMET primary specsheet](https://search.kemet.com/download/specsheet/C0603C102J5GACTU) directly on 2026-09-29. It confirms C0603C102J5GACTU: 1000pF, ±5%, 50V, C0G, 0603/1608. No part substitution was required. All passive primary specifications are now resolved. Original ESP32 DevKit remains external; no replacement ESP32 family is authorized.

Bare-board fabrication readiness is established by the geometry, export and rule checks. Component selection has a credible typical capacitance margin; first-power qualification still requires confirming effective capacitance/part identity, inspecting soldering and polarity, and current-limited analog bring-up with JP_ADC open. C6 reference settling/noise and system performance remain unmeasured.

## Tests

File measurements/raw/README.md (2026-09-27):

# Actual hardware data only

**TBD — requires fabricated hardware.** No measurements have been collected.

Record timestamped CSV sessions here after bench setup and calibration. Files are ignored by default to prevent accidental publication; intentionally publish selected, reviewed data with its instrument, circuit revision, gain, calibration, light source and test conditions. Keep synthetic fixtures in software tests and simulation outputs in simulation, never here.

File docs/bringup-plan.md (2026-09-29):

# Revision A bring-up and characterization

All physical results: **TBD — HARDWARE MEASUREMENT REQUIRED**. Simulation results are not acceptance measurements. Log board revision, fitted parts, gain shunt, instruments, ambient light, temperature, supply, calibration and acquisition settings with each result.

**Before powered bring-up:** qualify C2 to retain at least 0.47 µF effective capacitance at 3.3 V, including DC bias, tolerance, temperature and aging. Typical manufacturer curves support the part choice but do not guarantee each lot; obtain adequate manufacturer qualification or sample measurements. Characterize C6 effective capacitance and verify its reference settling/noise during controlled bring-up before accepting performance. Keep the locked values and packages; see the [footprint and capacitor review](../hardware/manufacturing/rev-a/footprint-review.md).

1. **Visual inspection, power off.** Check OPA2320 pin 1, TPS7A2033PDBVR orientation, BPW34 cathode, BAT54S orientation, solder bridges and flux residue. Verify J1 against the contract, not a DevKit header's physical order. Close exactly one of JP2/JP3/JP4 (10 kΩ/100 kΩ/1 MΩ); leave JP1 (ADC connection) open. Inspect both board faces and clean the sensitive input region.
2. **Resistance checks.** Check VBUS_5V–GND, 3V3A–GND and 3V3D–GND for persistent near-shorts, allowing capacitors to charge. Confirm the selected feedback path with power removed; semiconductor paths can affect readings. Check connector continuity and ensure 3V3A and 3V3D are not shorted together.
3. **Analog rail.** Use a current-limited 5 V source with JP1 open. Set an initial 20 mA limit for the analog board alone; the ESP32 requires a separate appropriate current budget. Expect approximately 6 mA analog quiescent current by calculation, not a pass/fail measurement. Stop for unexpected heating or persistent current limiting. Measure TP_3V3A; compare with the regulator tolerance and measured input voltage.
4. **Reference.** After at least 0.5 s, measure TP_VREF near 1.65 V and check ripple. Never add a large capacitor directly to the reference buffer output. Verify the divider midpoint only with a high-impedance instrument.
5. **Dark baseline.** Shield BPW34 completely and measure TP_TIA, TP_FILTER and TP_ADC. Expect near VREF with gain-dependent dark/offset shift. Record the actual baseline for each gain; do not substitute nominal 1.650 V in precision current calculations.
6. **Oscillation.** Use a short scope ground spring at TP_TIA and TP_FILTER; inspect at high bandwidth and multiple time scales, including startup and each gain. Do not probe SUM with an ordinary capacitive probe. Stop if there is sustained oscillation, unexpected ringing or clipping.
7. **Photodiode response.** Apply weak controlled LED illumination. Output must decrease with increasing light. Use a resistor/current-limited LED driver; do not drive a high-current LED directly from a GPIO. Document wavelength, source drive and fixed mechanical geometry. Optical intensity is uncalibrated unless independently characterized.
8. **Three ranges.** Power off before moving the one gain shunt. Repeat baseline and response for 10 kΩ, 100 kΩ and 1 MΩ. To measure transimpedance accurately, use a calibrated injected current or independently characterized optical current. Fit ΔV/ΔI and record uncertainty; comparing an uncalibrated LED setting does not establish absolute gain.
9. **Saturation and bandwidth.** Increase controlled input toward the 0.25 V operating floor, then modestly beyond it to characterize recovery. Keep ADC disconnected during initial overload tests. Sweep a small sinusoidal modulation through the useful band and past the system −3 dB point (~310 Hz simulated). Normalize against measured input amplitude; source/LED roll-off must not be attributed to the TIA. Record clipping, bandwidth and recovery separately from simulation.
10. **ADC connection and calibration.** With JP1 open, power both boards from the intended common source, confirm common ground, J1 pin 3=DevKit 3V3D, and inspect rail ramps. The BAT54S clamps do not isolate an unpowered ESP32. Never hot-plug; open JP1 for independent powering. For ADC-only calibration, keep **JP1 / JP_ADC OPEN** and inject a current-limited DC source at **J1 pin 5 (ADC_LINK), the isolated ESP32/GPIO34 side**, **not TP_ADC or the actively driven filter output**, to avoid fighting the filter output. Measure the injected voltage with a DMM at ≥5 points across 0.25–2.40 V; retain raw counts, reported mV and DMM mV. Load the correction table in Python. Power down, remove the source, then fit JP1. Out-of-window values are invalid, not photocurrent measurements.
11. **Wi-Fi comparison.** Compare dark analog-output spectra and ADC records with Wi-Fi off/on and representative streaming load, especially at 1 MΩ. Use external instrumentation for the analog noise floor; the ESP32 ADC may dominate by orders of magnitude. Record actual sample timing, dropped counts and network conditions. Check connection loss/reconnection without joining separate epochs.
12. **WebSocket streaming and CSV capture.** Connect the Python dashboard to `ws://<esp32-ip>:81/` and use its `--record` option to save a CSV session. Verify JSON v1 batches and equal-length `raw`, `mv` and `dt_us` arrays. Record timestamped sessions with raw counts, baseline calibrated mV, correction-table provenance, gain and device timestamps. Match firmware gain metadata to the physical shunt. Verify all three ranges and default 4 ksps. Characterize 1–8 ksps settings separately; low sample rates provide weaker alias rejection.
13. **FFT/noise.** Use a stationary, gap-free dark record for noise estimation and a separate known-tone record for FFT accuracy. Inspect timing before FFT; reject discontinuities instead of treating irregular samples as uniform. Report bandwidth, record length, window, detrending, PSD units, total/AC RMS and DC baseline. PSD containing a signal is not a dark-noise measurement. Retain data and scripts; never relabel mock-server output as measured.

## Measurement register

| Result | Status |
|---|---|
| Rails, current, VREF and startup sequencing | TBD — HARDWARE MEASUREMENT REQUIRED |
| Dark offsets, gain and maximum non-clipping current | TBD — HARDWARE MEASUREMENT REQUIRED |
| Stability, bandwidth, peaking and overload recovery | TBD — HARDWARE MEASUREMENT REQUIRED |
| Dark noise, Wi-Fi coupling and temperature drift | TBD — HARDWARE MEASUREMENT REQUIRED |
| ADC calibration residuals, timing, losses and sustained throughput | TBD — HARDWARE MEASUREMENT REQUIRED |

The ADC-only calibration injection point above clarifies the contract's shorthand “DC source → TP_ADC”: with JP1 open, TP_ADC remains connected to the analog driver. Inject at the isolated ADC_LINK side for ADC calibration. No locked electrical value or connectivity is changed.

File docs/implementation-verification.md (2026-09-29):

# Rev A implementation verification

Baseline: analog design gate PASS at `b1b1bc1`. This report concerns implementation; it does not repeat or replace the analog analysis. All hardware performance results remain **TBD — HARDWARE MEASUREMENT REQUIRED**.

| Check | Required evidence | Status |
|---|---|---|
| Schematic | KiCad ERC with no unresolved violations | **PASS** 2026-09-29: `--severity-all` ERC 0 errors / 0 warnings, no exclusions (fresh parent run; preserved export baseline [erc.rpt](../hardware/manufacturing/rev-a/exports/erc.rpt)). Netlist-export annotation warning resolved (numeric refs; contract names in Value) |
| Critical pin mappings | Independent exported-netlist check for OPA2320, TPS7A2033, BAT54S, BPW34 and connector | **PASS**: `tools/check_hardware_contract.py` on [schematic.xml](../hardware/kicad/verification/schematic.xml). Negative tests (renamed TIA_OUT, swapped D1 pins) fail as intended. Capture recipe regenerates an identical netlist. Visual PDF check of D1, U1A, D2 and gain links done |
| PCB | Parent-run DRC with all severities and schematic parity | **PASS** 2026-09-29; 0 violations, 0 unconnected, 0 parity issues |
| Analog placement | Parent visual and geometric review of actual saved PCB | PASS for prototype fabrication; see notes below |
| Firmware | Parent-run build using pinned PlatformIO environment | **PASS** 2026-09-29: regression build, 70,480 B RAM / 780,037 B flash; espressif32@7.1.3 + Arduino-ESP32 2.0.17, 0 warnings, RAM 21.5 %, flash 59.5 %. Not flashed: runtime timing and Wi-Fi throughput are **TBD — HARDWARE MEASUREMENT REQUIRED** |
| Python | Parent-run offline tests and synthetic capture/analysis smoke check | **PASS** 2026-09-29: 7 pytest tests (3.74 s). CLI smoke: mock server → dashboard `--record` → `analysis_fft.py` recovered the SYNTHETIC 10 Hz / 50 mV tone. Firmware emits all 10 contract keys |
| Fabrication package | BOM, seven Gerbers, plated and nonplated drills; independent review and hash verification | **PASS**: 7 Gerbers, 41 PTH holes and 4 NPTH mounting holes. Parent source/output manifest hashes and BOM netlist reference/quantity coverage PASS; see [manufacturing notes](../hardware/manufacturing/rev-a/fabrication-notes.md) and [footprint review](../hardware/manufacturing/rev-a/footprint-review.md) |
| Publishing | No secrets or restricted vendor models; repository content and publication checks | Hardware package `c5b42ac` committed/pushed; repository content check PASS. Documentation is included in the commit containing this report; final post-push acceptance checks are clean working tree and HEAD equal to origin/main |

ERC and DRC are necessary checks, not evidence of measured noise, stability, ADC accuracy or RF immunity. The approved simulation remains model evidence. Fabrication release requires reviewing the actual board and exact purchased parts; this task does not place an order.

## Parent manual layout review

Reviewed the actual native board, final top render and pad/track geometry. BPW34 anode/input separation is 3.42 mm, shortened from approximately 7 mm; SUM branches total 22.72 mm and use no vias. Three feedback pairs are clustered, with the highest-gain pair closest to the input. The longer output-side connections to manual selection headers remain a documented layout tradeoff, not a measured parasitic-capacitance result. Both-layer copper-pour keepout follows SUM and feedback; digital connector and 5 V routing are at the opposite side. VREF uses front copper without vias. Local amplifier bypasses have short ground fanouts.

All 25 vias were checked against SMD pad bounding boxes: minimum drill-edge separation is 0.375 mm (minimum copper-edge separation 0.225 mm). No filled/capped via-in-pad process is required. Cathode/pin-1 markings, accessible test pads, gain shunts, ADC link and connector orientation were inspected. Numeric assembly references remain on F.Fab and the assembly drawing. The source board is 60 × 45 mm, 2 layers and nominal 1.6 mm thickness.

Firmware regression emitted no new warnings in its successful incremental build. GPIO34, 11 dB attenuation, timer acquisition and WebSocket81 remain unchanged. Python regression passed all seven tests. Software and locked analog documents were not modified from the approved baseline.

## Fabrication release review

Independent inspection parsed all seven Gerber layers and both drill files. Top and bottom copper and solder mask were rendered and viewed: registration, pads and holes were plausible, with no observed missing tracks or mask. Edge.Cuts forms one closed 60 × 45 mm outline. Back silkscreen is intentionally empty; mounting holes are present. Source/output SHA-256 checks bind the reviewed native board to the export package. The BOM covers schematic references and quantities; manufacturer package/pin review is recorded in the linked footprint review.

Bare-board prototype fabrication review PASS. The specified capacitors retain their locked values and packages. Primary-source typical bias evidence supports the LDO output capacitance margin, but does not guarantee lot qualification. Effective capacitance, reference settling and actual LDO behavior remain component/physical qualification items. This release does not claim measured system performance.

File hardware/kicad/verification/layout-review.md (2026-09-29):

# Rev A PCB routing and analog review

Layout reviewed 2026-09-27; final DRC rerun 2026-09-28 with KiCad 9.0.0. The frozen native schematic was not edited.

## Executed verification

`kicad-cli pcb drc --severity-all --schematic-parity --exit-code-violations -o hardware/kicad/verification/drc.rpt hardware/kicad/photodiode-tia-esp32.kicad_pcb`

Exit code **0**: **0 DRC violations, 0 unconnected items, 0 schematic parity issues**. No DRC exclusions or severity suppression were added. Ground zones were filled before checking. Board is 60 × 45 mm, two copper layers, 1.6 mm nominal thickness; tracks 0.25 mm, vias 0.6/0.3 mm. Existing outline, mounting arrangement, functional floorplan and all schematic components were retained; defective crossing tracks were replaced and local courtyard conflicts repaired. All footprint library identifiers and schematic instance paths match the frozen schematic. Mounting holes are board-only.

## Manual analog assessment

- D1 BPW34 pad 2/anode connects to U1 pin 2/SUM; pad 1/cathode connects to 3V3A. U1/U2 remain OPA2320 SOIC-8; U3 remains the locked TPS7A2033PDBVR footprint/pin assignment. D2 remains BAT54S. Netlist parity verifies the connector and paired gain mappings.
- SUM was routed first entirely on front copper: **zero vias**, total branch copper length **22.72 mm** across the detector, amplifier and six feedback terminations. The direct detector-to-input distance is approximately 3.42 mm (D1 anode at 12.85,22.5 mm; U1 pin 2 at 15.525,20.365 mm); the remaining copper serves the three selectable pairs. It is a compact three-range prototype, not a measured minimum-capacitance layout.
- Each RF/CF pair is adjacent in the compact two-column, three-row cluster above the detector/TIA, with the 1 MΩ pair nearest the input. The gain selector is on the output side of each pair. Gain branch route lengths are 11.44/15.22/21.79 mm, with 0/0/1 layer transitions respectively; these output-side connections are a tradeoff of the retained manual header architecture. They are not part of the SUM node. Exactly one shunt is required.
- Front and back ground-pour keepout covers the feedback/SUM region using a shaped polygon around the feedback cluster (x=9.5–14 mm, y=9.8–19.8 mm) and the short input/detector connection (extending to x=16.8 mm and y=23.5 mm) to reduce shunt plane capacitance. The rest of the board has common filled ground planes. No digital or USB-power traces enter this region. The capacitance assumption still requires bench validation; DRC does not validate loop stability.
- U1/U2 100 nF decouplers sit immediately above their supply pads; each has a short explicit fanout to an off-pad ground via and the plane. Bulk 1 µF capacitors sit beside them. The reference divider and shunt capacitors remain beside U1B, with buffered VREF routed entirely on front copper. There is no added capacitive load on the buffer output.
- Filter flow remains left-to-right through R6/C12, U2A, R7/C13, U2B, R8/C14, BAT54S, JP1 and J1. The ADC/digital connector remains at the right edge. VBUS routing stays at x≥47.5 mm; 3V3D routing stays at x≥45 mm, away from the detector/TIA. Power and ground are connected, not only airwires or reserved routing channels.
- Reviewed `board-top.png`: no visible footprint/body conflicts, required gain/ADC power-off instructions and all six contract test-point names are readable. Standard 3D models render where installed; no BPW34 model is provided. Numeric references are visible on F.Fab and in `assembly-top.svg`, with contract names on the silkscreen. Cathode and IC pin-1 markings remain visible.

## Fabrication and bench handoff

This is a DRC-clean engineering prototype, not evidence of measured analog performance. The next manufacturing review should inspect the drill/mask exports and assembly drawings. All ground vias now use off-pad fanouts; signal vias also avoid SMD pad apertures. An executed geometric check found 25 total vias and at least 0.225 mm between via copper and every SMD-pad bounding box. This layout does not require filled/capped via-in-pad construction. Final fabrication review should still check the selected vendor’s mask, drill and assembly outputs.

Bench checks remain necessary: dark offset, all three gains, noise and oscillation, rail sequencing, reference voltage, ADC calibration and clamp behavior. All measured results remain TBD.

## Safe regeneration

The native PCB is the deliverable. `repair_pcb.py --output NEW_PATH` reads it and writes a separate candidate; it refuses to replace an existing output. It uses the board's existing footprints and the frozen netlist and does not require an absolute footprint-library path. Review any candidate and run full DRC before adopting it. The defective initial-placement recipe and intermediate boards are preserved only in ignored local recovery storage, not distributed as build instructions.

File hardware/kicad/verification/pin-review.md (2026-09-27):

# Rev A schematic verification and pin review

2026-09-27, KiCad CLI 9.0.0. Analog design gate b1b1bc1 was accepted; this capture does not revise it.

## Executed checks

- Native `.kicad_sch` loaded by KiCad CLI and exported successfully to PDF and XML netlist.
- `kicad-cli sch erc --severity-all --exit-code-violations -o verification/erc.rpt photodiode-tia-esp32.kicad_sch`: **0 errors, 0 warnings, exit 0**. No ERC exclusions, severity overrides, or hidden suppression were added.
- Exported `verification/schematic.pdf` rendered with Poppler and visually inspected for readable fields, complete section content, absence of title-block overlap, and correct diode/amp symbols.
- `verification/schematic.xml` is available for independent electrical-contract validation and PCB net import.
- **Annotation resolution (2026-09-27):** contract names without a trailing number (JP_G10K, TP_3V3A, …) are treated by KiCad as *unannotated*. Netlist export printed `schematic has annotation errors`, and GUI Update-PCB-from-Schematic would be blocked. This was an annotation issue, not an electrical fault. Fixed by numeric references with the contract name in the Value field: J1=J_ESP32, JP1=JP_ADC, JP2=JP_G10K, JP3=JP_G100K, JP4=JP_G1M, TP1=TP_3V3A, TP2=TP_VREF, TP3=TP_TIA, TP4=TP_FILTER, TP5=TP_ADC, TP6=TP_GND. Connectivity is unchanged: the regenerated netlist is identical in nets and components apart from the references. `tools/check_hardware_contract.py` resolves contract names through Value. Negative tests (renamed TIA_OUT net, swapped BPW34 pins) fail as expected.
- The earlier report of 3 ERC warnings is not reproducible from any saved file. Fresh `--severity-all` ERC on this schematic reports 0 errors and 0 warnings with no exclusions.
- Hardware measurements remain TBD. ERC verifies schematic rules, not analog performance or assembly correctness.

## Manufacturer pin review

| Device | Primary source checked | Captured pins and package |
|---|---|---|
| U1, U2 OPA2320 | [TI SBOS513F, p4](https://www.ti.com/lit/ds/symlink/opa2320.pdf), D/DGK diagram and OPA2320 pin table | SOIC-8: 1 OUT A, 2 −IN A, 3 +IN A, 4 V−/GND, 5 +IN B, 6 −IN B, 7 OUT B, 8 V+/3V3A. Unit C is the explicit power unit, with real power-input pin types. |
| U3 TPS7A2033PDBVR | [TI SBVS338H, p4, DBV diagram/table](https://www.ti.com/lit/ds/symlink/tps7a20.pdf) | SOT-23-5: 1 IN/VBUS_5V, 2 GND, 3 EN/VBUS_5V, 4 NC, 5 OUT/3V3A. Pin 4 has native no-connect electrical type and no wire. DQN pinout is different and was not used. |
| D2 BAT54S | [Vishay 86410 Rev1.1, p1 top-view diagram](https://www.vishay.com/docs/86410/bat54_bat54a_bat54c_bat54s.pdf), PDF rendered and inspected | SOT-23: 1 lower anode/GND, 2 upper cathode/3V3D, 3 series midpoint/ADC_OUT. Thus GND → diode → ADC_OUT → diode → 3V3D. |
| D1 BPW34 | [Vishay 81521 Rev2.1, p4 package drawing](https://www.vishay.com/docs/81521/bpw34.pdf), PDF rendered and inspected | Project convention pad1=K/3V3A; pad2=A/SUM. The manufacturer identifies A/C and a cathode marking, rather than numeric pin identifiers. Footprint pad1 is rectangular and marked K. 5.1 mm lead pitch; body envelope 4.65 × 4.3 mm, 1 mm drill for 0.7(+0.1) ×0.3 mm leads. Confirm physical marking before insertion. |

## Exact electrical mapping

- U1: 1 TIA_OUT, 2 SUM, 3 VREF, 4 GND, 5 VREF_DIV, 6 VREF, 7 VREF, 8 3V3A.
- U2: 1 BUF1, 2 BUF1, 3 LP1, 4 GND, 5 LP2, 6 FILTER_OUT, 7 FILTER_OUT, 8 3V3A.
- R1/C3: 10k/1n, SUM ↔ GAIN_10K; JP2 (JP_G10K): 1 GAIN_10K, 2 TIA_OUT.
- R2/C4: 100k/100p, SUM ↔ GAIN_100K; JP3 (JP_G100K): 1 GAIN_100K, 2 TIA_OUT.
- R3/C5: 1M/10p, SUM ↔ GAIN_1M; JP4 (JP_G1M): 1 GAIN_1M, 2 TIA_OUT.
- R4 3V3A–VREF_DIV and R5 VREF_DIV–GND, both 10k 0.1%; C6 10u and C7 100n from VREF_DIV to GND. No output capacitor on VREF.
- R6 TIA_OUT–LP1; C12 LP1–GND. R7 BUF1–LP2; C13 LP2–GND. R8 FILTER_OUT–ADC_OUT; C14 ADC_OUT–GND.
- C1 VBUS_5V–GND, C2 3V3A–GND, each 1u X7R. C8/C9 (U1), C10/C11 (U2): 100n + 1u 3V3A–GND.
- J1 (J_ESP32) 1 VBUS_5V, 2 GND, 3 3V3D, 4 GND, 5 ADC_LINK, 6 GND. JP1 (JP_ADC) 1 ADC_OUT, 2 ADC_LINK.
- TP1–TP6 (values TP_3V3A, TP_VREF, TP_TIA, TP_FILTER, TP_ADC, TP_GND) follow the locked contract; no SUM test pad.
- Power flags identify externally driven VBUS_5V, 3V3D and GND at the header. The LDO's actual power-output pin drives 3V3A; no power flag masks analog-rail connectivity.

All populated components have assigned footprints. Standard KiCad 9 footprint libraries plus the checked-in `Photodiode.pretty` library are required. No schematic or board fabrication release is implied.

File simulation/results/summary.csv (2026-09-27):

gain | RF_ohm | dc_gain_ohm | dc_gain_dbohm | bw_tia_hz | bw_adc_hz | peaking_tia_db | peaking_adc_db | phase_margin_deg | loop_crossover_hz | small_step_overshoot_pct | small_step_settle_1pct_s | overload_recovery_2pct_s | dark_Vtia_V | dark_Vadc_V | Vtia_min_V | Vtia_max_V | Vadc_min_V | Vadc_max_V | i_at_0p25V_A | i_at_rail_A | adc_noise_integrated_rms_V | input_ref_noise_density_100Hz_A_rtHz | flag_marginal
10k/1n | 10000.0 | 9999.997487964947 | 79.99999781807381 | 15878.66451788064 | 309.54834859689157 | 4.928480734633922e-09 | 0.0 | 79.38946962605733 | 12683142.19166389 | 0.0 | 4.6059381677815974e-05 | 6.406939888534482e-05 | 1.650009036064148 | 1.6500669717788696 | 0.011775468476116657 | 1.650009036064148 | 0.011830617673695087 | 1.6500669717788696 | 0.0001400029328177521 | nan | 1.5749888364653969e-06 | 2.2639561666343224e-12 | False
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

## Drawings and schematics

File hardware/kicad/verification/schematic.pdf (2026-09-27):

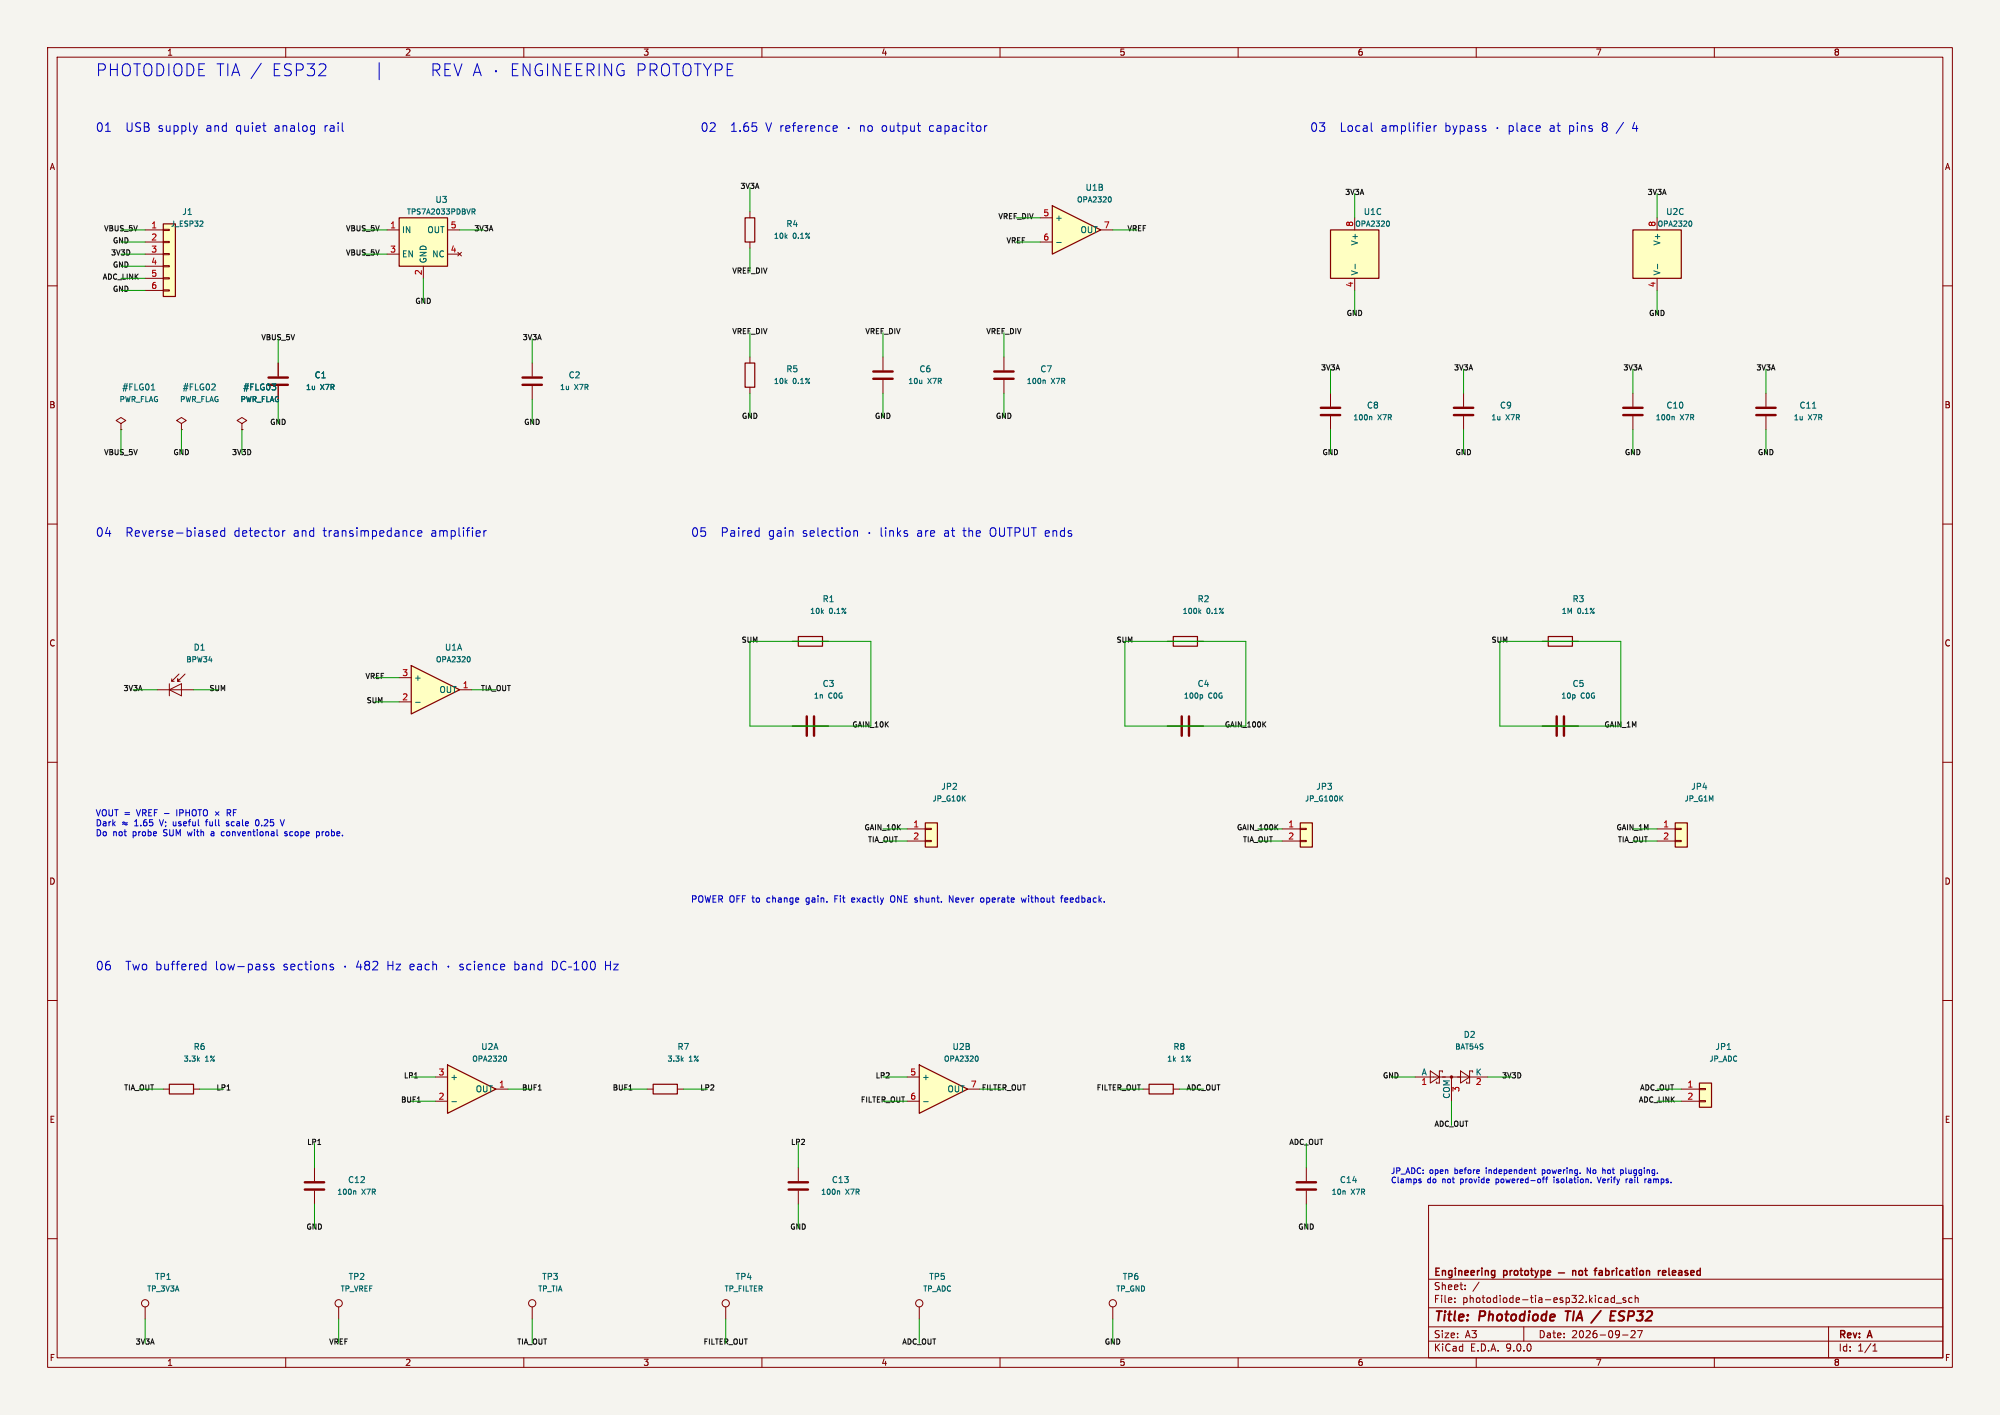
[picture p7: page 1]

Id: 1/1 Title: Photodiode TIA / ESP32

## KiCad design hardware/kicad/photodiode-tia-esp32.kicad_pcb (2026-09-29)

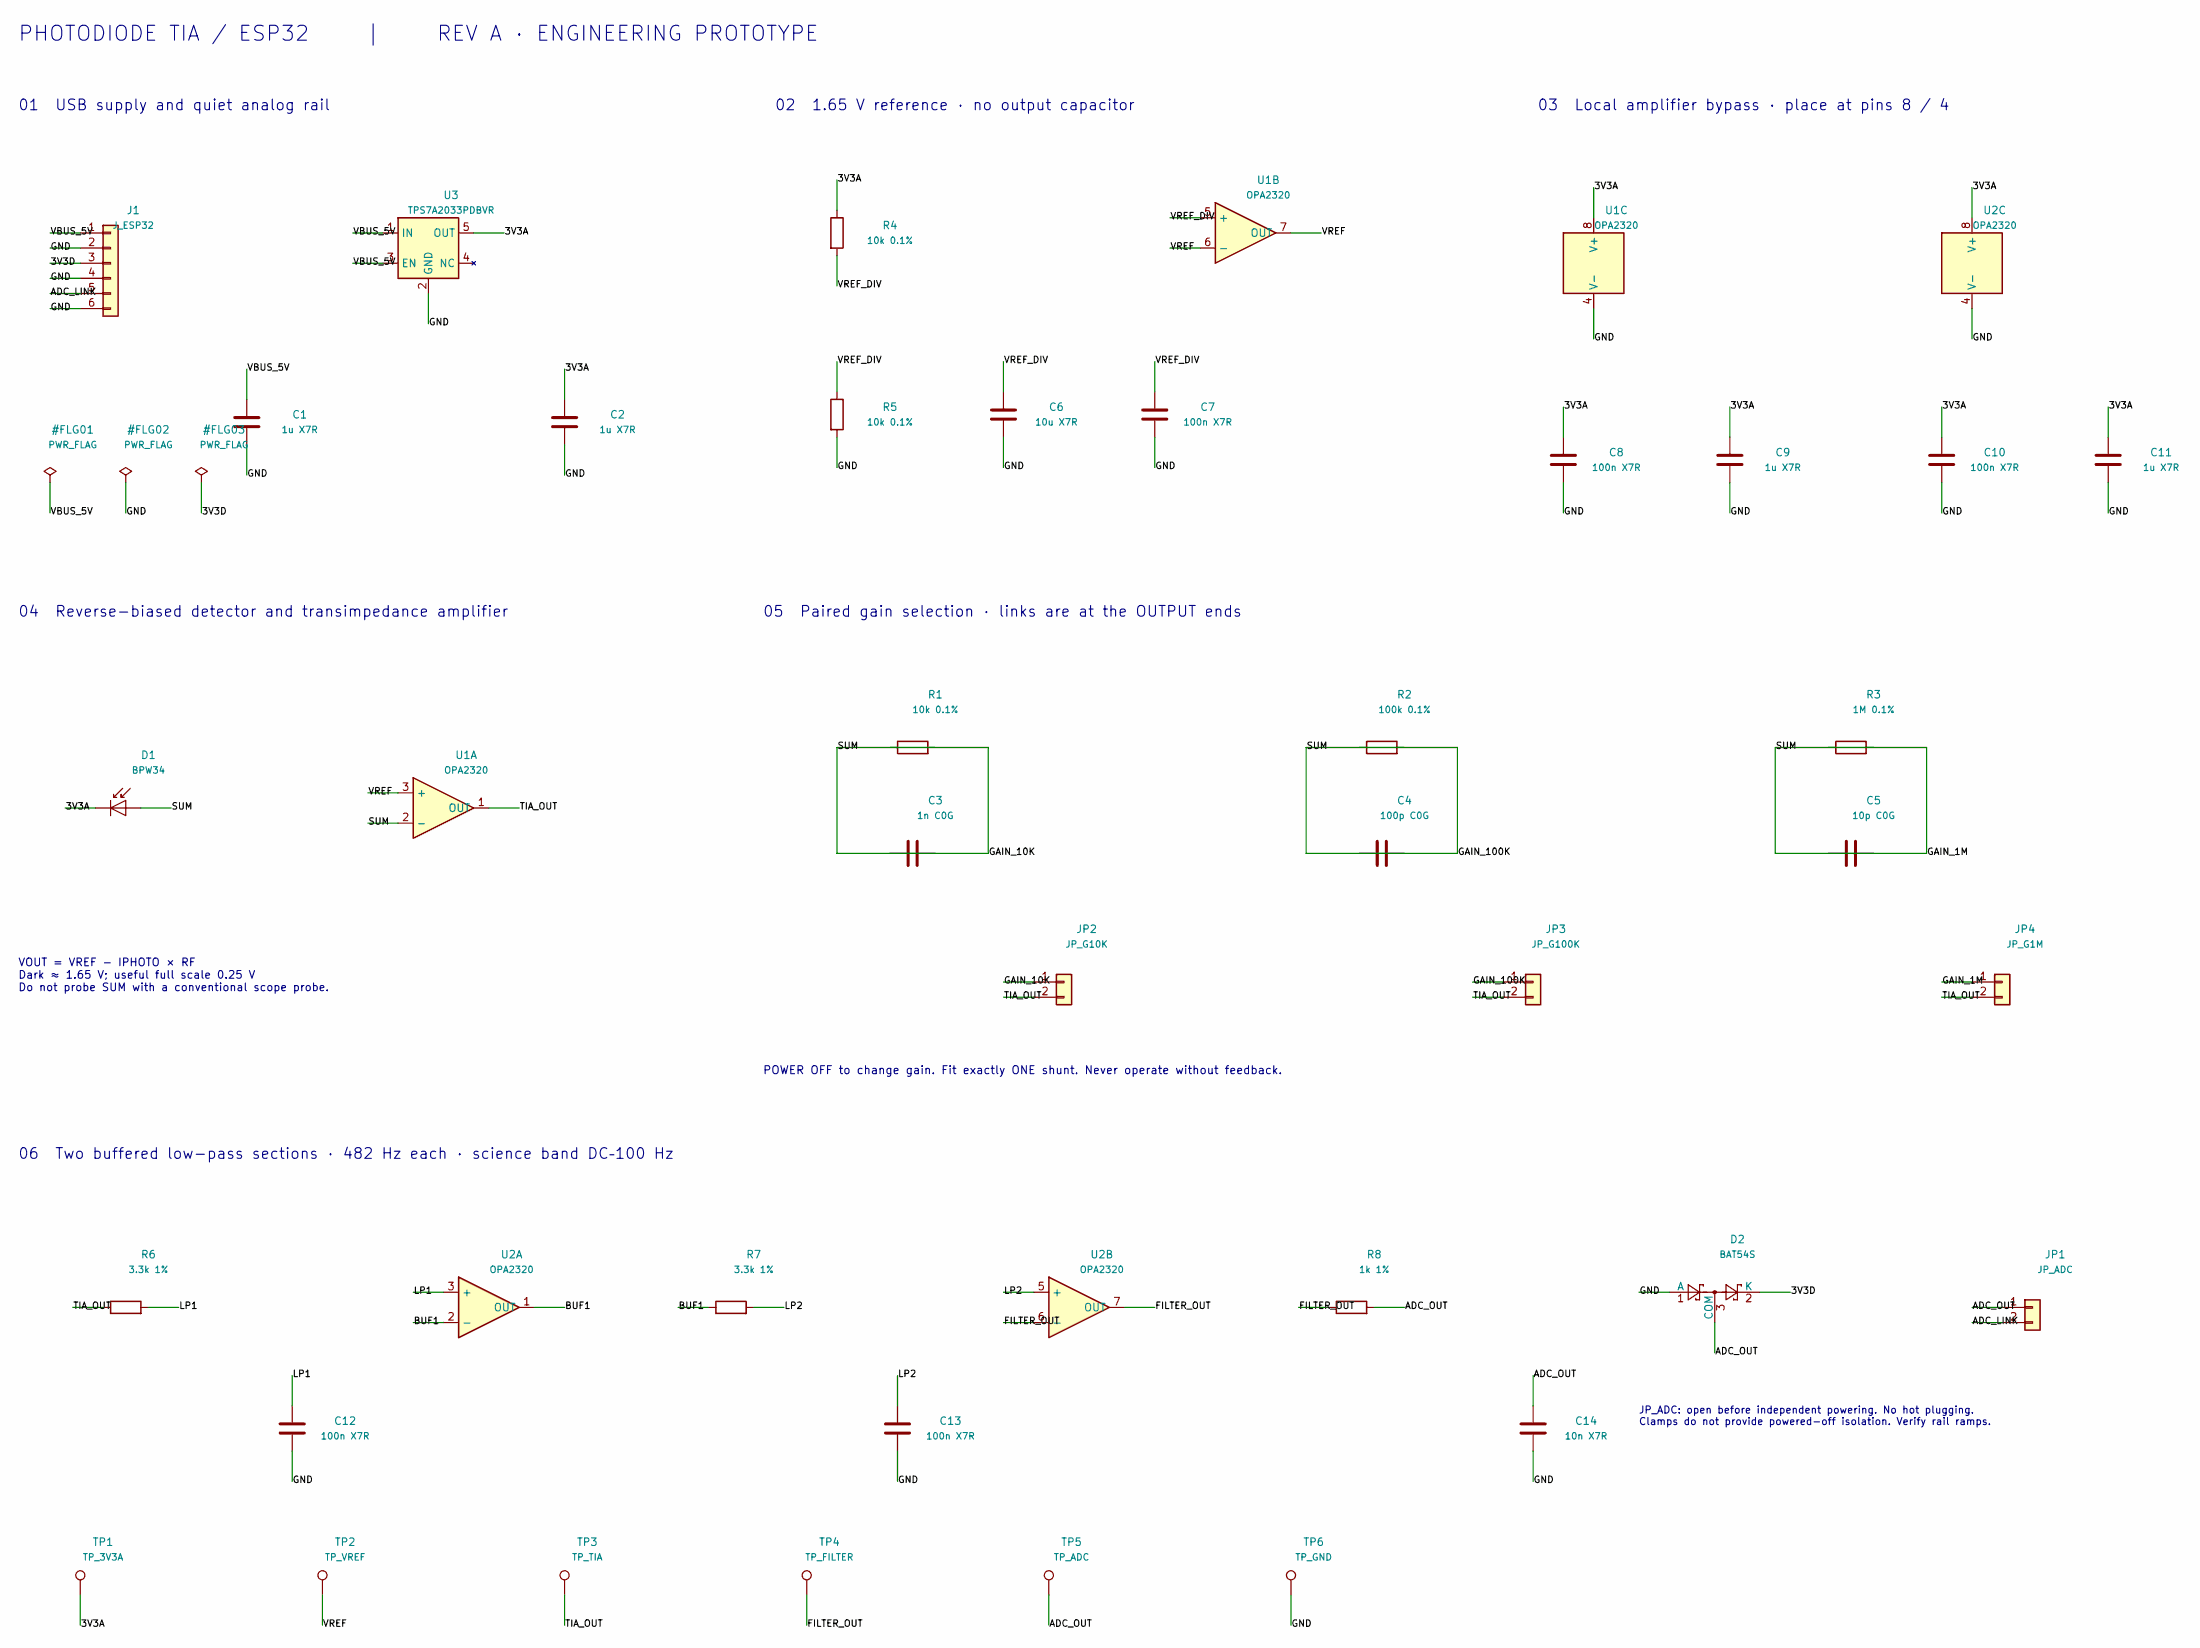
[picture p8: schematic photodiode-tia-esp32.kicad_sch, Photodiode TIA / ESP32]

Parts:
C1, C2, C9, C11: 1u X7R; C_0603_1608Metric
C3: 1n C0G; C_0603_1608Metric
C4: 100p C0G; C_0603_1608Metric
C5: 10p C0G; C_0603_1608Metric
C6: 10u X7R; C_0603_1608Metric
C7, C8, C10, C12, C13: 100n X7R; C_0603_1608Metric
C14: 10n X7R; C_0603_1608Metric
D1: BPW34; Vishay_BPW34_THT
D2: BAT54S; SOT-23
J1: J_ESP32; PinHeader_1x06_P2.54mm_Vertical
JP1: JP_ADC; PinHeader_1x02_P2.54mm_Vertical
JP2: JP_G10K; PinHeader_1x02_P2.54mm_Vertical
JP3: JP_G100K; PinHeader_1x02_P2.54mm_Vertical
JP4: JP_G1M; PinHeader_1x02_P2.54mm_Vertical
R1, R4, R5: 10k 0.1%; R_0603_1608Metric
R2: 100k 0.1%; R_0603_1608Metric
R3: 1M 0.1%; R_0603_1608Metric
R6, R7: 3.3k 1%; R_0603_1608Metric
R8: 1k 1%; R_0603_1608Metric
TP1: TP_3V3A; TestPoint_Pad_D1.5mm
TP2: TP_VREF; TestPoint_Pad_D1.5mm
TP3: TP_TIA; TestPoint_Pad_D1.5mm
TP4: TP_FILTER; TestPoint_Pad_D1.5mm
TP5: TP_ADC; TestPoint_Pad_D1.5mm
TP6: TP_GND; TestPoint_Pad_D1.5mm
U1, U2: OPA2320; SOIC-8_3.9x4.9mm_P1.27mm
U3: TPS7A2033PDBVR; SOT-23-5

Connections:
/3V3A: C2.1, C8.1, C9.1, C10.1, C11.1, D1.1 (K), R4.1, TP1.1, U1.8 (V+), U2.8 (V+), U3.5 (OUT)
/3V3D: D2.2 (K), J1.3
/ADC_LINK: J1.5, JP1.2
/ADC_OUT: C14.1, D2.3 (COM), JP1.1, R8.2, TP5.1
/BUF1: R7.1, U2.1 (OUT), U2.2 (−)
/FILTER_OUT: R8.1, TP4.1, U2.6 (−), U2.7 (OUT)
/GAIN_1M: C5.1, JP4.1, R3.1
/GAIN_10K: C3.1, JP2.1, R1.1
/GAIN_100K: C4.1, JP3.1, R2.1
/GND: C1.2, C2.2, C6.2, C7.2, C8.2, C9.2, C10.2, C11.2, C12.2, C13.2, C14.2, D2.1 (A), J1.2, J1.4, J1.6, R5.2, TP6.1, U1.4 (V−), U2.4 (V−), U3.2 (GND)
/LP1: C12.1, R6.2, U2.3 (+)
/LP2: C13.1, R7.2, U2.5 (+)
/SUM: C3.2, C4.2, C5.2, D1.2 (A), R1.2, R2.2, R3.2, U1.2 (−)
/TIA_OUT: JP2.2, JP3.2, JP4.2, R6.1, TP3.1, U1.1 (OUT)
/VBUS_5V: C1.1, J1.1, U3.1 (IN), U3.3 (EN)
/VREF: TP2.1, U1.3 (+), U1.6 (−), U1.7 (OUT)
/VREF_DIV: C6.1, C7.1, R4.2, R5.1, U1.5 (+)

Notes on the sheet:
PHOTODIODE TIA / ESP32 | REV A · ENGINEERING PROTOTYPE
01 USB supply and quiet analog rail
02 1.65 V reference · no output capacitor
03 Local amplifier bypass · place at pins 8 / 4
04 Reverse-biased detector and transimpedance amplifier
VOUT = VREF − IPHOTO × RF Dark ≈ 1.65 V; useful full scale 0.25 V Do not probe SUM with a conventional scope probe.
05 Paired gain selection · links are at the OUTPUT ends
POWER OFF to change gain. Fit exactly ONE shunt. Never operate without feedback.
06 Two buffered low-pass sections · 482 Hz each · science band DC–100 Hz
JP_ADC: open before independent powering. No hot plugging. Clamps do not provide powered-off isolation. Verify rail ramps.

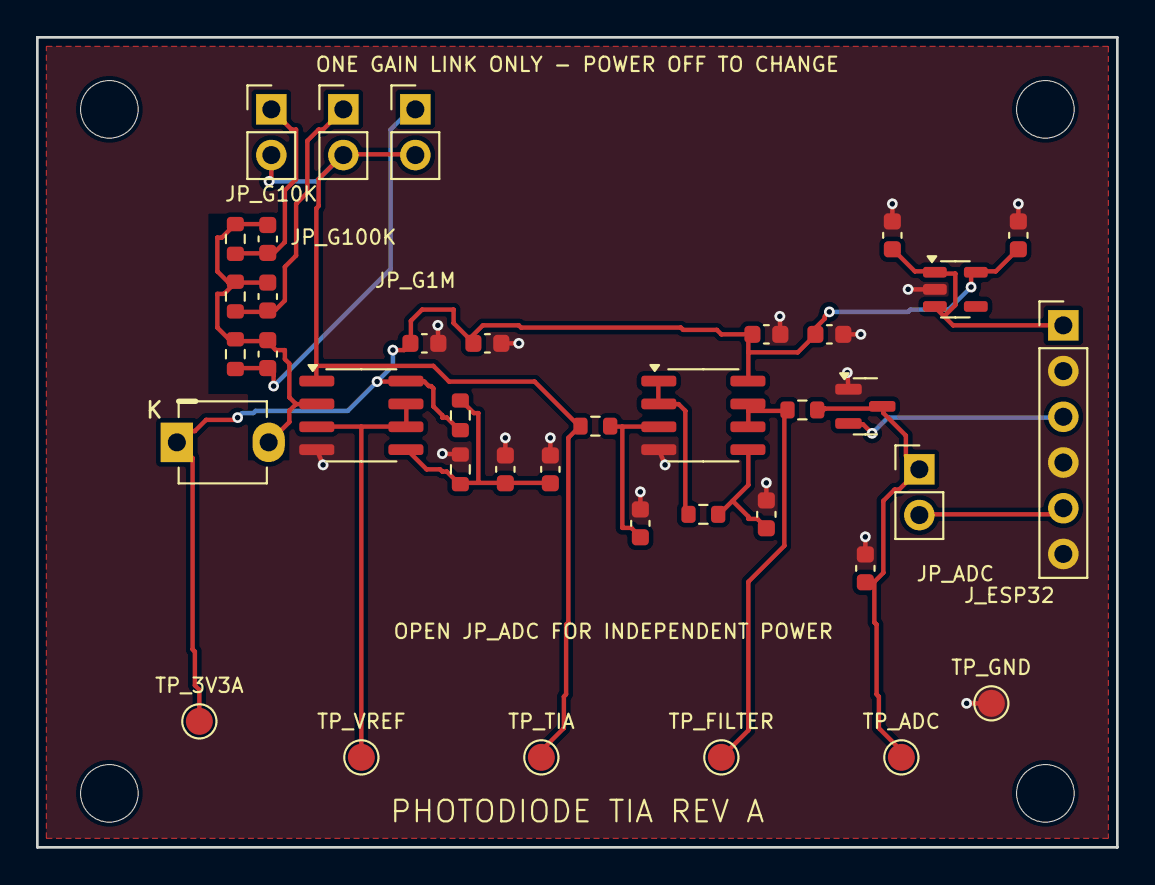
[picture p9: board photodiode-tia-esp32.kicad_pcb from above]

Board: 2 copper layers, 60.0 x 45.0 mm, 42 parts (0 on the bottom side), 17 nets.

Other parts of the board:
MH1, MH2, MH3, MH4: M3; MountingHole_3.2mm_M3

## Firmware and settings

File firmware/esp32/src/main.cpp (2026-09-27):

// Photodiode-TIA-ESP32 Rev A firmware entry point.
// See README.md for build/flash instructions and the timing/protocol
// design rationale, and docs/design-contract.md for the electrical and
// wire-protocol contract this implements.

#include <Arduino.h>

#include "acquisition.h"
#include "config.h"
#include "console.h"
#include "telemetry.h"

void setup() {
  Serial.begin(SERIAL_BAUD);
  delay(100); // let the USB-serial bridge settle before the first prints

  acquisition::begin();
  telemetry::begin();
  console::begin();
}

void loop() {
  console::poll();
  // Nothing time-critical runs here: acquisition happens in its own
  // high-priority task driven by a hardware timer ISR, and streaming
  // happens in its own lower-priority task. This loop only services the
  // serial console, so a short yield is fine.
  delay(1);
}

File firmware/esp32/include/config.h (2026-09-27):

#pragma once
// Rev A firmware configuration.
// See docs/design-contract.md for the electrical/protocol contract this
// implements. Keep these values in sync with that document.

#include <stdint.h>
#include "hal/adc_types.h"

// ---------------------------------------------------------------------------
// ADC front end
// ---------------------------------------------------------------------------
// GPIO34 is ADC1 channel 6 on the original ESP32 (fixed silicon mapping;
// changing the pin means changing the channel too).
#define ADC_INPUT_GPIO       34
#define ADC_INPUT_UNIT       ADC_UNIT_1
#define ADC_INPUT_CHANNEL    ADC_CHANNEL_6
#define ADC_INPUT_ATTEN      ADC_ATTEN_DB_12   // contract "11 dB": same setting, renamed DB_12 in IDF 4.4.5+; ~0.15-2.45 V usable window
#define ADC_INPUT_BITWIDTH   ADC_WIDTH_BIT_12   // 12-bit, 0-4095 counts

// ---------------------------------------------------------------------------
// Acquisition timing
// ---------------------------------------------------------------------------
#define SAMPLE_RATE_HZ_DEFAULT   4000u
#define SAMPLE_RATE_HZ_MIN       1000u
#define SAMPLE_RATE_HZ_MAX       8000u

// ---------------------------------------------------------------------------
// Batching / ring buffer
// ---------------------------------------------------------------------------
#define BATCH_SIZE             256u   // samples per emitted packet (64 ms @ 4 ksps)
#define RING_BUFFER_SLOTS      10u    // >=8 batches required by contract; extra margin absorbs Wi-Fi jitter

// ---------------------------------------------------------------------------
// Gain metadata (manual; must match the installed JP_G10K/JP_G100K/JP_G1M jumper)
// ---------------------------------------------------------------------------
#define GAIN_OHM_DEFAULT   100000u
// Allowed set is enforced in code: {10000, 100000, 1000000}

// ---------------------------------------------------------------------------
// FreeRTOS task configuration
// ---------------------------------------------------------------------------
#define ACQUISITION_TASK_PRIORITY   (configMAX_PRIORITIES - 2)
#define ACQUISITION_TASK_CORE       1
#define ACQUISITION_TASK_STACK      4096

#define TELEMETRY_TASK_PRIORITY     2
#define TELEMETRY_TASK_CORE         0
#define TELEMETRY_TASK_STACK        6144

// ---------------------------------------------------------------------------
// Networking
// ---------------------------------------------------------------------------
#define WEBSOCKET_PORT       81
#define JSON_BUFFER_BYTES    8192   // sized for BATCH_SIZE=256 worst-case raw+mv+dt_us digits

// ---------------------------------------------------------------------------
// Serial console
// ---------------------------------------------------------------------------
#define SERIAL_BAUD   115200

// ---------------------------------------------------------------------------
// Diagnostics (never applied to the streamed raw/mv arrays)
// ---------------------------------------------------------------------------
#define DIAG_AVG_N_MAX   64

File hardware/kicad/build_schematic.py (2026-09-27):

"""Deterministic native KiCad 9 schematic authoring; writes only schematic/library files."""
from pathlib import Path
import uuid,re,json,math,os,argparse
parser=argparse.ArgumentParser(description=__doc__)
parser.add_argument("--symbol-library",type=Path,default=None)
parser.add_argument("--overwrite",action="store_true",help="Replace schematic and local symbol library; discard manual edits")
args=parser.parse_args()
P=Path(__file__).resolve().parent
if (P/'photodiode-tia-esp32.kicad_sch').exists() and not args.overwrite:
 raise SystemExit('Schematic exists. Native schematic is source of truth; use --overwrite only to deliberately discard manual edits.')
candidates=[args.symbol_library,Path(os.environ['KICAD_SYMBOL_DIR']) if os.environ.get('KICAD_SYMBOL_DIR') else None,Path('/usr/share/kicad/symbols'),Path('/Applications/KiCad/KiCad.app/Contents/SharedSupport/symbols'),Path('C:/Program Files/KiCad/9.0/share/kicad/symbols')]
LIB=next((p for p in candidates if p and (p/'Device.kicad_sym').exists()),None)
if LIB is None:raise SystemExit('Pass --symbol-library PATH or set KICAD_SYMBOL_DIR to KiCad 9 symbol library.')
def uid(s): return str(uuid.uuid5(uuid.NAMESPACE_URL,'photodiode-tia-reva/'+s))
def q(s):return json.dumps(str(s),ensure_ascii=False)
def eff(sz=1.27):return f'(effects (font (size {sz} {sz})))'
def block(text,start):
 i=start;d=0;quoted=False;esc=False
 for j in range(start,len(text)):
  c=text[j]
  if c=='"' and not esc:quoted=not quoted
  if not quoted:
   if c=='(':d+=1
   elif c==')':
    d-=1
    if d==0:return text[start:j+1]
  esc=c=='\\' and not esc
symbols={};pins={}
def standard(lib,name):
 t=(LIB/(lib+'.kicad_sym')).read_text(); b=block(t,t.index('(symbol "'+name+'"'))
 symbols[name]=b
 pp=[]
 for m in re.finditer(r'\(pin (\w+) (\w+)\s',b):
  p=block(b,m.start()); at=re.search(r'\(at ([\d.-]+) ([\d.-]+) ([\d.-]+)\)',p);n=re.search(r'\(number "([^"]+)"',p)
  pp.append((n[1],float(at[1]),float(at[2]),float(at[3])))
 pins[name]={1:pp};return name
for l,n in [('Device','R'),('Device','C'),('Sensor_Optical','BPW34'),('Diode','BAT54S'),('Connector_Generic','Conn_01x06'),('Connector_Generic','Conn_01x02'),('Connector','TestPoint'),('power','PWR_FLAG')]:standard(l,n)
def pin(n,name,x,y,a,t='passive'):
 return f'(pin {t} line (at {x} {y} {a})(length 2.54)(name {q(name)} {eff()})(number {q(n)} {eff()}))'
def custom(name,units,graphics,ref='U'):
 b=f'(symbol "{name}" (pin_names (offset 0.508))(in_bom yes)(on_board yes)(property "Reference" "{ref}" (at 0 10 0) {eff()})(property "Value" "{name}" (at 0 7 0) {eff()})'
 pins[name]={}
 for u,ps in units.items():
  b+=f'(symbol "{name}_{u}_1" '+graphics[u]+''.join(pin(*p) for p in ps)+')'
  pins[name][u]=[(str(p[0]),p[2],p[3],p[4]) for p in ps]
 symbols[name]=b+')'
tri='(polyline (pts (xy -5.08 5.08)(xy 5.08 0)(xy -5.08 -5.08)(xy -5.08 5.08))(stroke (width 0.254)(type default))(fill (type background)))'
rect='(rectangle (start -5.08 5.08)(end 5.08 -5.08)(stroke (width 0.254)(type default))(fill (type background)))'
custom('OPA2320',{1:[(3,'+',-7.62,2.54,0,'input'),(2,'−',-7.62,-2.54,0,'input'),(1,'OUT',7.62,0,180,'output')],2:[(5,'+',-7.62,2.54,0,'input'),(6,'−',-7.62,-2.54,0,'input'),(7,'OUT',7.62,0,180,'output')],3:[(8,'V+',0,7.62,270,'power_in'),(4,'V−',0,-7.62,90,'power_in')]},{1:tri,2:tri,3:rect})
custom('TPS7A2033PDBVR',{1:[(1,'IN',-7.62,2.54,0,'power_in'),(3,'EN',-7.62,-2.54,0,'input'),(5,'OUT',7.62,2.54,180,'power_out'),(4,'NC',7.62,-2.54,180,'no_connect'),(2,'GND',0,-7.62,90,'power_in')]},{1:rect})
root=uid('root');items=[];manifest=[]
def wire(a,b):items.append(f'(wire (pts (xy {a[0]} {a[1]})(xy {b[0]} {b[1]}))(stroke (width 0)(type default))(uuid {q(uid("wire"+str((a,b))))}))')
def label(net,x,y):items.append(f'(label {q(net)} (at {x} {y} 0) {eff(1.1)} (uuid {q(uid("label"+str((net,x,y))))}))')
def note(s,x,y,size=1.5):items.append(f'(text {q(s)} (at {x} {y} 0)(effects (font (size {size} {size}))(justify left))(uuid {q(uid("note"+s))}))')
def add(name,ref,val,x,y,nets,fp='',unit=1,angle=0,autolabel=True):
 inst=uid(ref+str(unit));a=math.radians(angle)
 b=f'(symbol (lib_id "Photodiode:{name}")(at {x} {y} {angle})(unit {unit})(in_bom yes)(on_board yes)(dnp no)(uuid {q(inst)})'
 tx,ty=(x+8.89,y-1.27) if name in ['R','C'] and angle==0 else (x+3.81,y-8.89)
 b+=f'(property "Reference" {q(ref)} (at {tx} {ty} {angle}) {eff()})'
 b+=f'(property "Value" {q(val)} (at {tx} {ty+2.54} {angle}) {eff(1.1)})'
 b+=f'(property "Footprint" {q(fp)} (at {x} {y} 0)(effects (font(size 1.27 1.27))(hide yes)))'
 coords={}
 for n,px,py,pa in pins[name][unit]:
  X=round(x+px*math.cos(a)-py*math.sin(a),4);Y=round(y-px*math.sin(a)-py*math.cos(a),4);coords[n]=(X,Y)
  b+=f'(pin {q(n)} (uuid {q(uid(ref+"pin"+n))}))'
  net=nets.get(n)
  if net is None:continue  # U3 NC is explicitly a no_connect electrical pin
  if autolabel:
   aa=math.radians(pa+angle);ex=round(X-5.08*math.cos(aa),4);ey=round(Y+5.08*math.sin(aa),4)
   wire((X,Y),(ex,ey));label(net,ex,ey)
 b+=f'(instances (project "photodiode-tia-esp32" (path "/{root}" (reference {q(ref)})(unit {unit})))))';items.append(b)
 if unit==1:manifest.append({'ref':ref,'value':val,'footprint':fp})
 return coords
R='Resistor_SMD:R_0603_1608Metric';C='Capacitor_SMD:C_0603_1608Metric';SO='Package_SO:SOIC-8_3.9x4.9mm_P1.27mm';H='Connector_PinHeader_2.54mm:PinHeader_1x02_P2.54mm_Vertical'
def passive(kind,ref,val,x,y,n1,n2,angle=0):return add(kind,ref,val,x,y,{'1':n1,'2':n2},R if kind=='R' else C,angle=angle)
note('PHOTODIODE TIA / ESP32     |     REV A · ENGINEERING PROTOTYPE',20,15,2.5)
note('01  USB supply and quiet analog rail',20,27,1.8)
add('Conn_01x06','J1','J_ESP32',35.56,53.34,dict(zip(map(str,range(1,7)),['VBUS_5V','GND','3V3D','GND','ADC_LINK','GND'])),'Connector_PinHeader_2.54mm:PinHeader_1x06_P2.54mm_Vertical')
add('TPS7A2033PDBVR','U3','TPS7A2033PDBVR',88.9,50.8,{'1':'VBUS_5V','2':'GND','3':'VBUS_5V','4':None,'5':'3V3A'},'Package_TO_SOT_SMD:SOT-23-5')
passive('C','C1','1u X7R',58.42,80.01,'VBUS_5V','GND');passive('C','C2','1u X7R',111.76,80.01,'3V3A','GND')
for i,(net,x) in enumerate([('VBUS_5V',25.4),('GND',38.1),('3V3D',50.8)]):add('PWR_FLAG','#FLG0'+str(i+1),'PWR_FLAG',x,90.17,{'1':net})
note('02  1.65 V reference · no output capacitor',147,27,1.8)
passive('R','R4','10k 0.1%',157.48,48.26,'3V3A','VREF_DIV');passive('R','R5','10k 0.1%',157.48,78.74,'VREF_DIV','GND')
passive('C','C6','10u X7R',185.42,78.74,'VREF_DIV','GND');passive('C','C7','100n X7R',210.82,78.74,'VREF_DIV','GND')
add('OPA2320','U1','OPA2320',226.06,48.26,{'5':'VREF_DIV','6':'VREF','7':'VREF'},SO,unit=2)
note('03  Local amplifier bypass · place at pins 8 / 4',275,27,1.8)
for ref,x in [('U1',284.48),('U2',347.98)]:add('OPA2320',ref,'OPA2320',x,53.34,{'8':'3V3A','4':'GND'},SO,unit=3)
for ref,v,x in [('C8','100n X7R',279.4),('C9','1u X7R',307.34),('C10','100n X7R',342.9),('C11','1u X7R',370.84)]:passive('C',ref,v,x,86.36,'3V3A','GND')
note('04  Reverse-biased detector and transimpedance amplifier',20,112,1.8)
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

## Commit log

2026-09-27 docs: lock interface fields in design contract
    Add connector, buffer, calibration, framework and CF-sweep scope fields.
    Keep the TI vendor model out of Git and document its source and checksum.
2026-09-27 analog: complete calculation review and lock LDO and clamp parts
    Analytical CF (45 deg and Butterworth) across CT/GBW corners, per-gain
    ranges, noise budget including supply coupling and ADC, op-amp check.
    Review result: PASS. Lock TPS7A2033PDBVR and BAT54S in the contract.
    [analog_calcs.py]
2026-09-27 simulation: validate TIA stability and noise; pass analog design gate
    LTspice suite with the TI OPAx320 model: DC, AC, loop gain, transient,
    noise, VREF startup and supply coupling; CF sweeps at 0.5/1/2x both the
    analytical minimum and the selected values across CT 40-120 pF; GBW
    10-30 MHz with a behavioral model. Fix loop-gain extraction and VREF
    netlists that contradicted the contract. Gate: ANALOG DESIGN REVIEW PASS.
    [summary.csv]
2026-09-27 hardware: capture analog schematic with clean ERC and annotation
    KiCad 9 schematic, project symbol/footprint libraries, pin review against
    manufacturer datasheets, exported netlist/PDF and ERC report (0 errors,
    0 warnings, no exclusions). Symbolic contract names that KiCad treats as
    unannotated now live in Value with numeric references (J1, JP1-JP4,
    TP1-TP6). Add independent netlist contract check with negative tests
    and credential/vendor-model publication checks.
    [photodiode-tia-esp32.kicad_sch]
2026-09-27 firmware: add ESP32 acquisition and telemetry
    Timer-driven ADC1 GPIO34 sampling with per-sample timestamps, ring
    buffer with cumulative loss accounting, eFuse-calibrated mV, JSON v1
    WebSocket batches on port 81, serial diagnostics. Pinned Arduino-ESP32
    2.0.17; builds without warnings (RAM 21.5 %, flash 59.5 %).
2026-09-27 software: add Python visualization and analysis
    Validated telemetry client, recorder, DMM calibration, live dashboard,
    SYNTHETIC mock server and noise/FFT/gain/frequency-response scripts.
    7 offline tests pass including WebSocket and mock-to-FFT end to end.
2026-09-29 hardware: finalize low-noise TIA PCB layout
    [photodiode-tia-esp32.kicad_pcb]
2026-09-29 hardware: add BOM and fabrication release package
    [photodiode-tia-esp32-B_Cu.gbl, photodiode-tia-esp32-B_Mask.gbs, photodiode-tia-esp32-B_Silkscreen.gbo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]
2026-10-12 feat: add live Flutter ESP32 telemetry dashboard
2026-10-12 Start phase-sensitive optical sensing research track
2026-10-12 Measure live ESP32 stream health and set verified demo rate
